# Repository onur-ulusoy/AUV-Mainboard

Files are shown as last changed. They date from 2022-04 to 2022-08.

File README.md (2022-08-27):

# Mainboard Hardware 

The Mainboard is the heart of our Autonomous Underwater Vehicle (AUV). This sophisticated board utilizes the power of the STM32H743 microcontroller, a high-performance device that serves as the brain of our AUV. The Mainboard's primary responsibilities are to facilitate real-time communication between various peripheral devices, translate high-level commands into specific device controls, distribute power to peripheral units, and provide robust system monitoring. Its unique role makes it a vital component in maintaining the smooth operation of the AUV, ensuring that each subsystem works in harmony to tackle the challenges of the underwater environment.

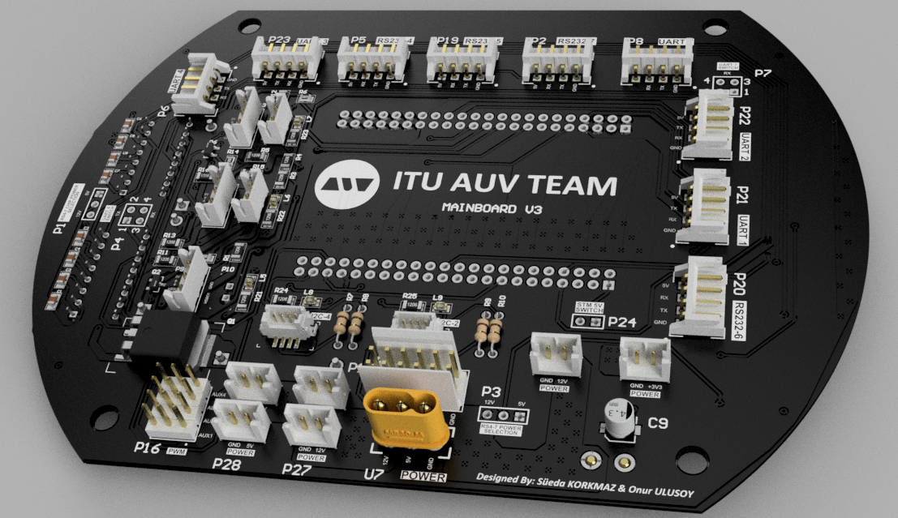
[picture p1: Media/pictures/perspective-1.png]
mb
<picture>    </picture>

This repository focuses Mainboard's hardware design. For more details on the firmware, visit the [Mainboard Firmware Repository](https://github.com/onur-ulusoy/auv-mainboard-firmware).

<picture>   dash </picture>

<p align="center">
    <a href="https://auv.itu.edu.tr/">
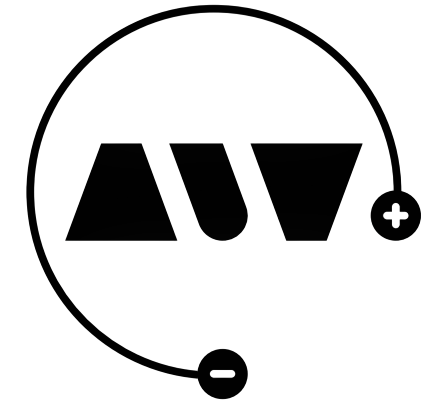
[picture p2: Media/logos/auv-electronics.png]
        
    </a>
</p>

<p align="center"><em >AUV Electronics 2022</em></p>

<picture>   dash </picture>

<p align="center">
    <a href="https://auv.itu.edu.tr/">
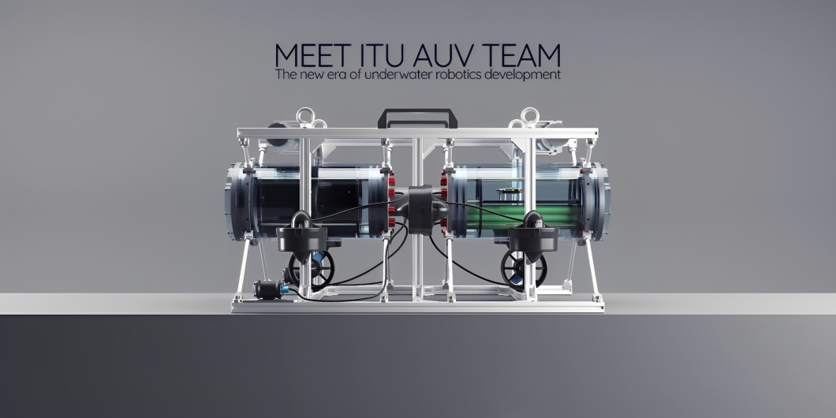
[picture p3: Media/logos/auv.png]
        
    </a>
</p>

<picture>   dash </picture>

<p align="center">
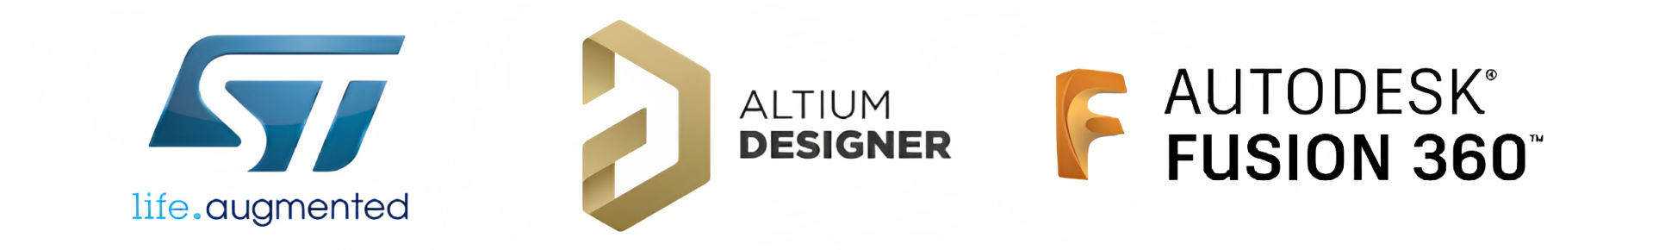
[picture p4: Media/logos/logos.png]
    
</p>

<picture>   dash </picture>

## Table of Contents
- [Mainboard Hardware](#mainboard-hardware)
  - [Table of Contents](#table-of-contents)
  - [Board Description](#board-description)
  - [Electronics Design](#electronics-design)
    - [Layer Structure](#layer-structure)
    - [Microcontroller](#microcontroller)
    - [Connectivity](#connectivity)
      - [UART](#uart)
      - [RS232](#rs232)
      - [I2C](#i2c)
    - [Power Circuits](#power-circuits)
      - [Power Inputs and Outputs](#power-inputs-and-outputs)
      - [High-Side Switch (HSS) Circuits](#high-side-switch-hss-circuits)
    - [Other Features](#other-features)
      - [PWM Channels](#pwm-channels)
      - [ADC's](#adcs)
    - [Selections](#selections)
      - [RS Power Chip Selection](#rs-power-chip-selection)
      - [STM 5V Switch](#stm-5v-switch)
      - [UART Switches](#uart-switches)
    - [Debug \& Lighting](#debug--lighting)
  - [Mechanical Design](#mechanical-design)
  - [Manufacturing](#manufacturing)
  - [Technologies Used](#technologies-used)
  - [Project Timeline](#project-timeline)
  - [License](#license)
  - [Gallery](#gallery)

## Board Description

Equipped with the high-performance microcontroller STM32H743, the Mainboard bridges the communication gap between the WARP Driver Board, the on-board computer Jetson Xavier, and other peripheral devices. This enables the Mainboard to effectively translate high-level system commands into specific device controls, ensuring optimal coordination among the various subsystems of the AUV.

Aside from its role as a communication facilitator, the Mainboard also handles the power management of the AUV. It distributes power to peripheral units via dedicated power headers, thereby maintaining a constant, controlled energy supply to each component. This power management function is vital for the reliable operation of each subsystem, ensuring they receive the correct power supply for their operations.

In an effort to strengthen diagnostics and status monitoring, the Mainboard is equipped with multiple LEDs, providing visual indicators of the system status and function. These visual indicators enhance system reliability by providing real-time feedback on the system's operation. Furthermore, they aid in troubleshooting by providing immediate visual cues on any parts of the system that may be experiencing issues.

## Electronics Design

For a comprehensive understanding of the Mainboard's intricate design and layout, you can always visit the [Schematic Sheets](/Schematic%20Sheets/). These detailed documents will provide you with valuable insights into the structure, connections, and functionalities of the board's various components.

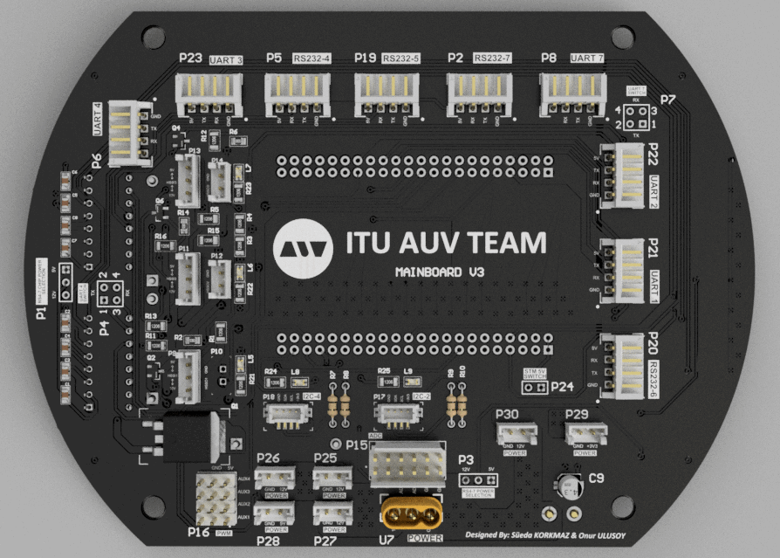
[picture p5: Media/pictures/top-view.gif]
<picture>    </picture>

### Layer Structure

Mainboard features a meticulously engineered 4-layer Printed Circuit Board (PCB) structure, designed using the advanced capabilities of Altium Designer. At the heart of the layout are the power and ground layers, smartly employed as inter-layers within the design.

These inter-layers serve more than just conducting electricity or acting as a return path. Their positioning within the inner layers of the board provides a close and uniform ground plane across the board, significantly reducing loop inductance for high-speed signals. This layout strategy inherently offers enhanced signal integrity and reduces the susceptibility of the board to electromagnetic interference (EMI), which could otherwise compromise the reliability and performance of the system.

Moreover, by sandwiching the power and ground planes between the outer signal layers, the PCB achieves a better thermal management. Heat generated by components mounted on the outer layers can be efficiently spread across the plane layers and dissipated, ensuring that the board components always remain within safe operating temperatures. This design is particularly critical in a demanding application environment such as an Autonomous Underwater Vehicle, where managing thermal behavior is crucial to maintain overall system reliability and longevity.

The 4-layer structure, thus, adds significant robustness to the Mainboard, enabling it to effectively support complex and power-intensive operations while ensuring optimal performance and safety.

For a more detailed examination of the board layers and the overall PCB structure, you can visit the file [MAINBOARD.PcbDoc](/MAINBOARD.PcbDoc).

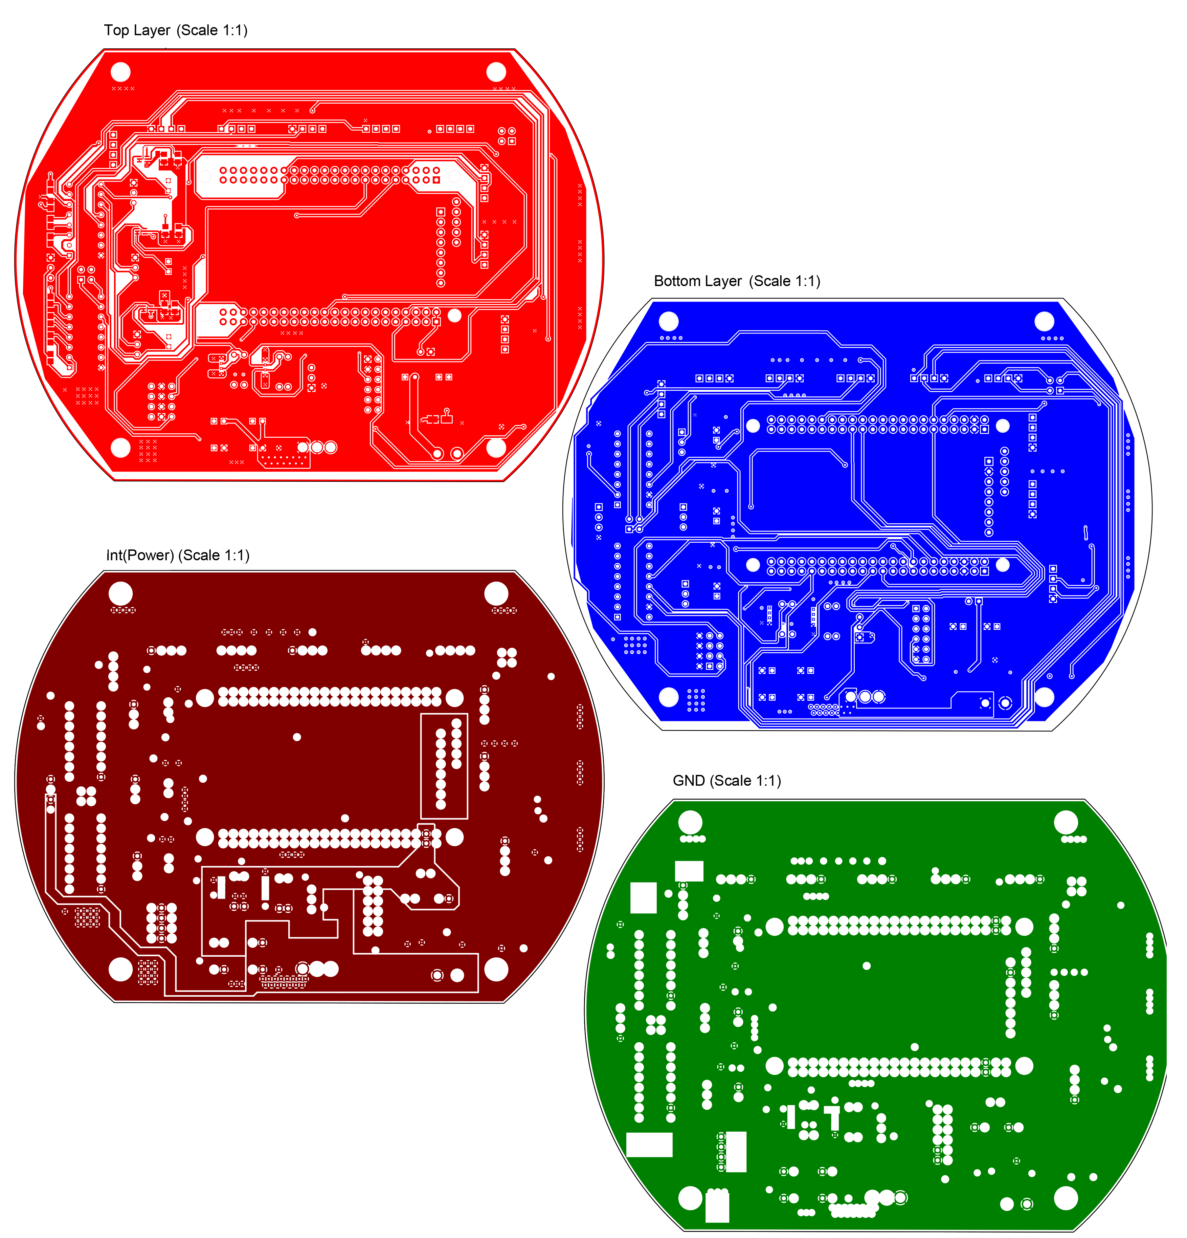
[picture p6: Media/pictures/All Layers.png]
<picture>    </picture>

### Microcontroller
At the heart of the Mainboard is an STM32H743 microcontroller, a powerful, high-performance device that provides the processing muscle needed to handle the complexities of operating an Autonomous Underwater Vehicle.

The firmware for the microcontroller has been developed and customized for the STM32H743, ensuring precise control and superior performance of the hardware. In order to manage tasks efficiently, we've integrated the FreeRTOS - a feature-rich real-time operating system. This system facilitates effective task scheduling and management, thereby ensuring that critical operations such as communication handling, power management, and device control are handled in a timely and efficient manner.

Just as it is with the WARP Driver Board, the priority with the Mainboard's microcontroller is to manage high-importance real-time tasks, such as power distribution and communication processing. FreeRTOS provides the necessary tools to ensure these tasks are dealt with promptly, while also maintaining the performance of lower-priority tasks. This symbiotic relationship between the microcontroller's firmware and the real-time operating system allows the Mainboard to perform its key tasks with optimal precision, efficiency, and reliability.

<p align="center">
    <a>
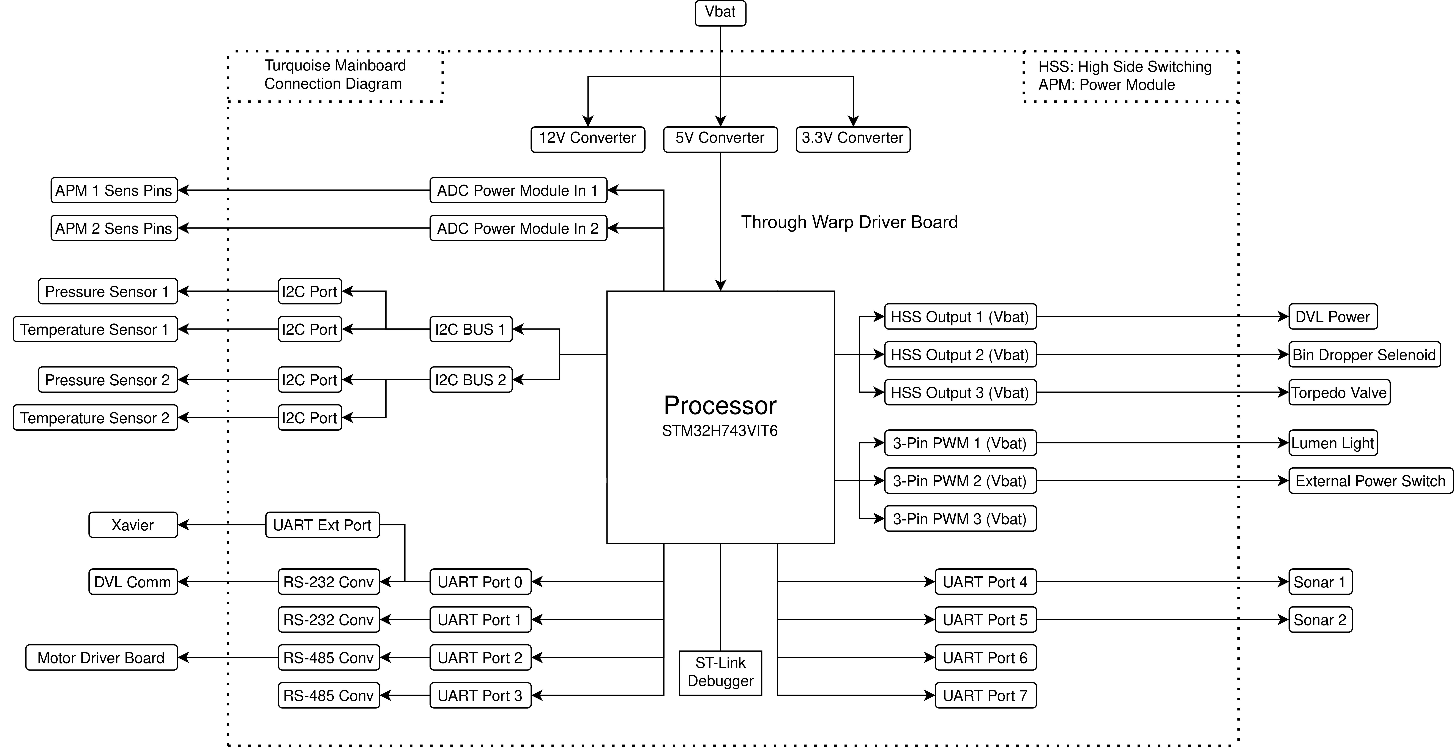
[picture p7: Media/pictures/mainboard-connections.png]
        
    </a>
</p>

### Connectivity
The Mainboard offers a wide range of connectivity options to interface with the various devices and subsystems that form the architecture of our AUV. This is essential for establishing efficient communication between the different units.

#### UART
The board is equipped with five UART (Universal Asynchronous Receiver/Transmitter) headers directly connected to the microcontroller. These headers primarily serve to establish communication with the sonars in our AUV system. The use of UART facilitates reliable data transfer, a crucial feature in our setup.

#### RS232
The Mainboard features four RS232 headers that are connected to the UARTs of the microcontroller via an RS232 interface IC. This arrangement is especially useful for long-distance communications as it can effectively resist electrical noise that may corrupt data. The RS232 interface is primarily used for communication with the Jetson Xavier, the DVL (Doppler Velocity Log), and the WARP Driver Board.

RS232 and UART Headers of the Mainboard:

<p align="center">
    <a>
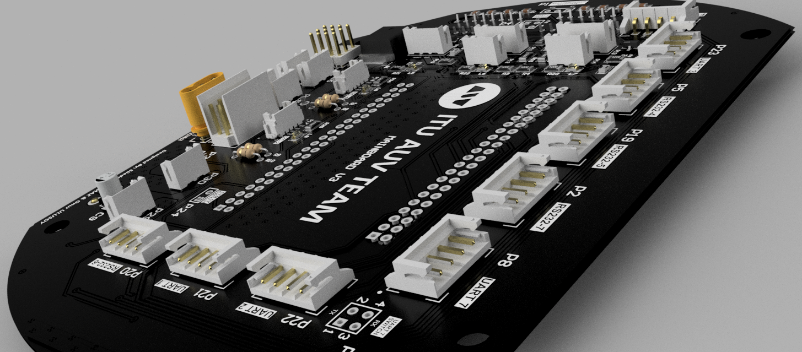
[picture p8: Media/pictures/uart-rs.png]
        
    </a>
</p>

#### I2C
In addition, the board includes two I2C (Inter-Integrated Circuit) headers, which are directly connected to the microcontroller. I2C is a highly effective method for short-distance communication and is utilized in this system for exchanging data with pressure and temperature sensors. This bus system enables the microcontroller to access and control these sensors, making real-time monitoring of the AUV's environment possible.The I2C circuits also have their own LEDs to provide real-time monitoring of communication status.

<p align="center">
    <a>
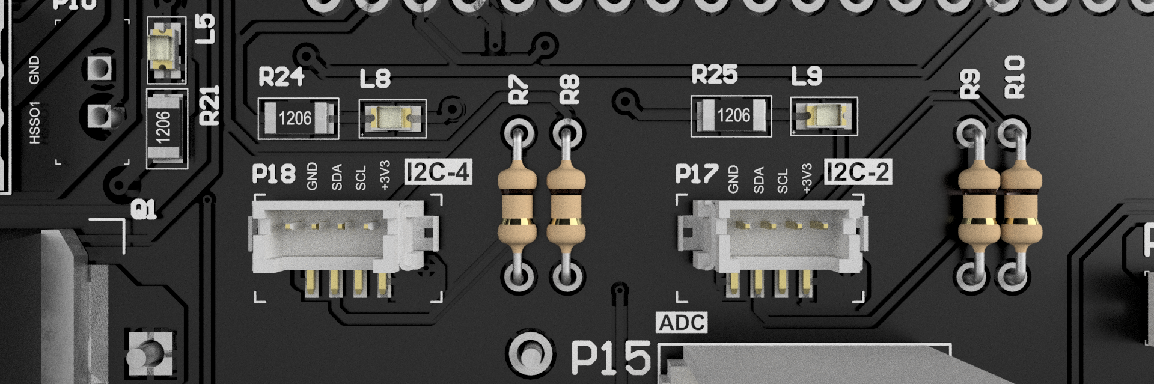
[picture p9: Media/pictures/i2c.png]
        
    </a>
</p>

### Power Circuits

#### Power Inputs and Outputs

The Mainboard is designed to receive power inputs of 12V and 5V, along with GND (ground). It possesses several power output connectors that can effectively power peripheral units such as the onboard computer, sensors, and its own microcontroller. These connectors ensure reliable and efficient power distribution across the system, supporting the operation of all connected devices.

<p align="center">
    <a>
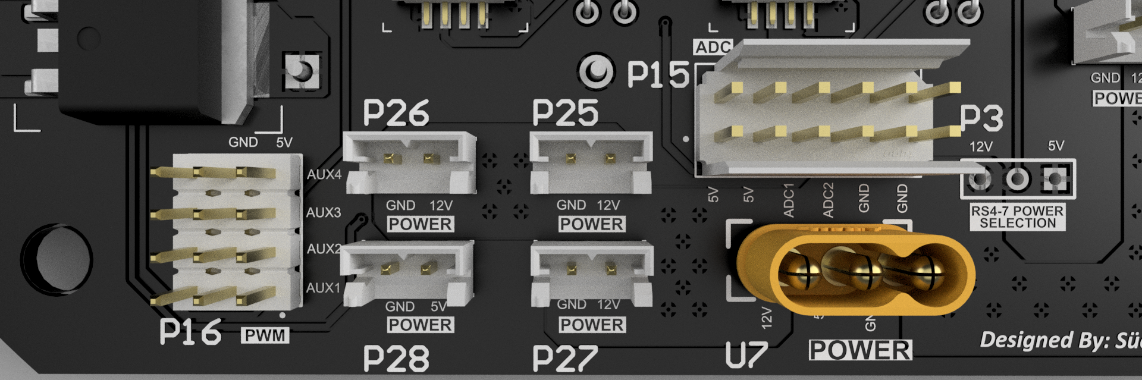
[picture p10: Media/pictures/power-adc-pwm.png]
        
    </a>
</p>

#### High-Side Switch (HSS) Circuits

The Mainboard is equipped with three High-Side Switch (HSS) circuits. These circuits are primarily used to control high-power loads, such as the bin dropper solenoid, the torpedo valve, and the Doppler Velocity Log (DVL). The HSS circuits can be powered with either 12V or 5V and are controlled through the GPIO pins of the microcontroller. They also have their own LEDs to provide real-time monitoring of their status. The HSS circuits provide safe and efficient switching operations, ensuring reliable control over these critical components of the AUV.

Selenoid driving with the HSS circuit in simulation can be seen below:

<p align="center">
    <a>
        
    </a>
</p>

3 HSS placement on the PCB:

<p align="center">
    <a>
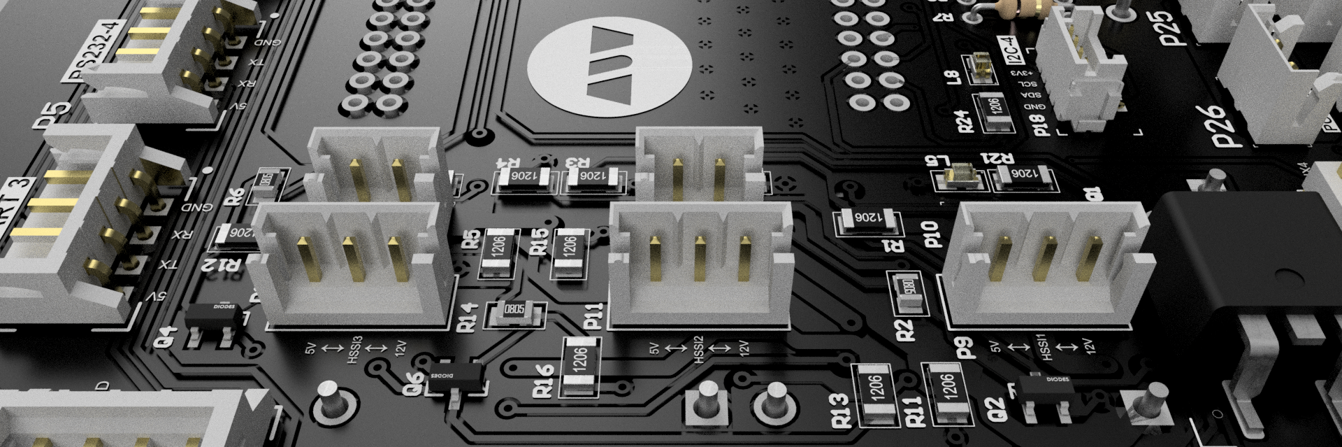
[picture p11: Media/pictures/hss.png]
        
    </a>
</p>

### Other Features

#### PWM Channels
The Mainboard provides support for three Pulse Width Modulation (PWM) channels. These channels can be utilized to drive and control peripheral components like the Lumen Light and an External power switch. The ability to manipulate the duty cycle of these signals offers precise control over these devices, allowing for adaptive operation according to varying underwater conditions.

#### ADC's
In addition to its various connectivity options, the Mainboard is equipped with two Analog to Digital Converters (ADCs) integrated within the microcontroller. These ADCs play a crucial role in the Sens APM function, converting the analog measurements into digital data for further processing and evaluation by the microcontroller.

### Selections

In the design of the Mainboard, much thought has been given to providing flexibility and configurability. Various selections have been included in the board's design to manage connections physically and ensure operational continuity.

#### RS Power Chip Selection

The Mainboard includes a selection feature for the RS power chip. This allows for a switch between different power chips as per the requirement, ensuring the most efficient operation for different devices connected via the RS232 interface.

<p align="center">
    <a>
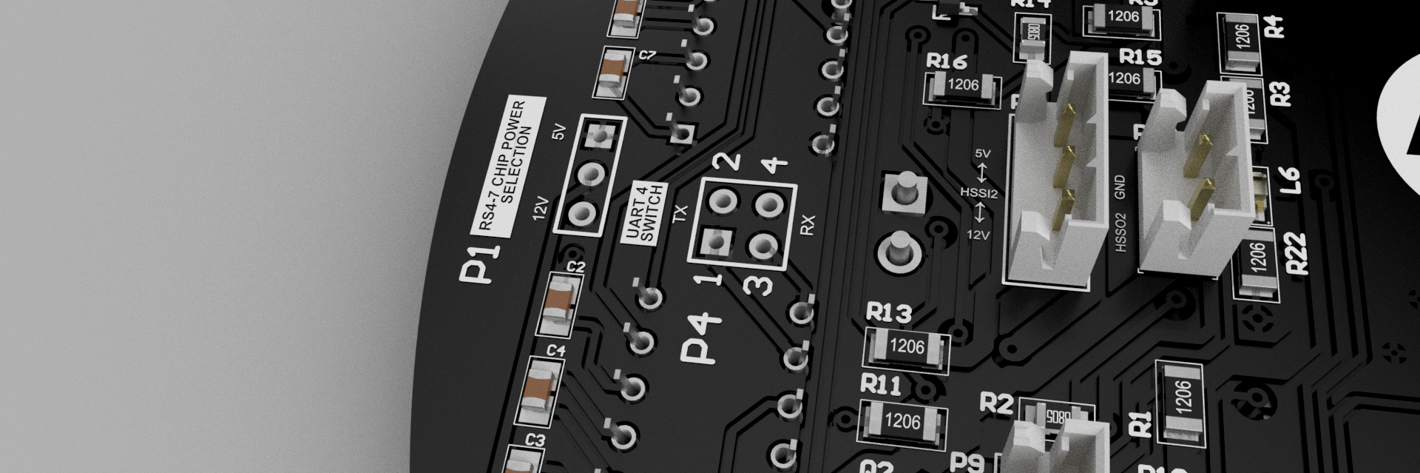
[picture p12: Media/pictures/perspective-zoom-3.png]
        
    </a>
</p>

#### STM 5V Switch

The Mainboard also has a provision to physically control the power supply to the STM32 microcontroller. With the STM 5V switch, the supply to the microcontroller can be turned on or off without affecting the rest of the board, useful for testing and debugging.

#### UART Switches

Furthermore, the board features UART switches to manage the connections with the devices interfaced through the UART headers. These switches enable direct control over the communication lines, allowing for convenient management of device connections. 

These selection features underscore the Mainboard's adaptability, allowing for a high degree of customization and control over the board's operation. They add an additional layer of robustness, enabling the board to continue operating efficiently even under changing conditions and requirements.

<p align="center">
    <a>
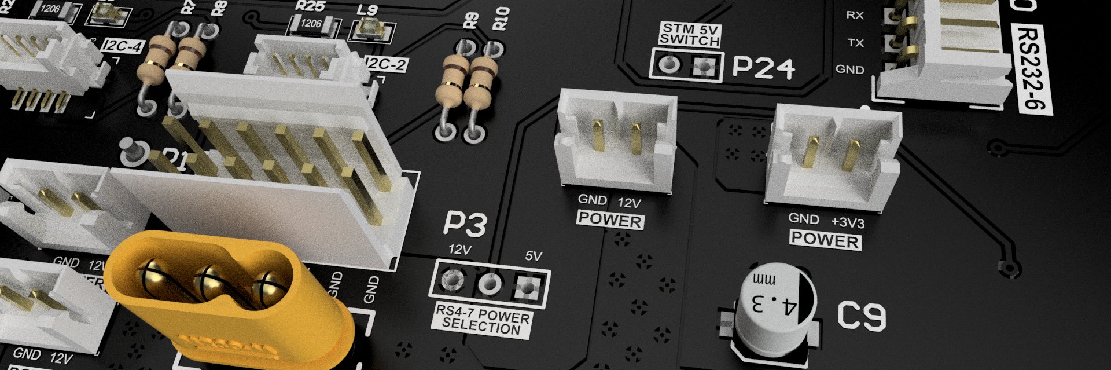
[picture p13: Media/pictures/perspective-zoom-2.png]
        
    </a>
</p>

### Debug & Lighting

Ensuring effective monitoring and debugging of the Mainboard is crucial to its smooth operation and management. To this end, the Mainboard has been designed with a comprehensive array of LEDs, which serve the dual purpose of debugging support and lighting enhancement.

<p align="center">
    <a>
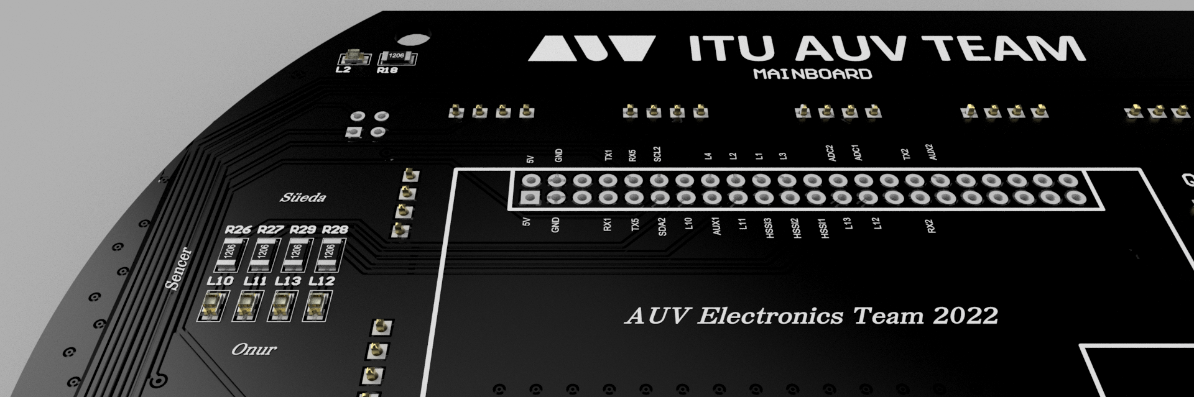
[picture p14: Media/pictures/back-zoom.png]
        
    </a>
</p>

## Mechanical Design

The mechanical design of the Mainboard is meticulously crafted to fit within the specific constraints of the Autonomous Underwater Vehicle (AUV). The board is designed to mount into the front tube of the AUV, matching the tube's form factor for an optimized fit.

This is achieved by fastening the board through four corner holes that align with the mounting points within the tube. This approach ensures that the Mainboard remains securely positioned during the AUV's underwater operations, allowing it to endure the potential rigors of the marine environment.

Moreover, this mechanical setup provides convenient accessibility to the board, which aids in the ease of maintenance and part replacements when required. The combination of a compact form factor and a secure mounting design allows the Mainboard to effectively fulfill its crucial roles in power distribution, communication, and control within the AUV.

<p align="center">
    <a>
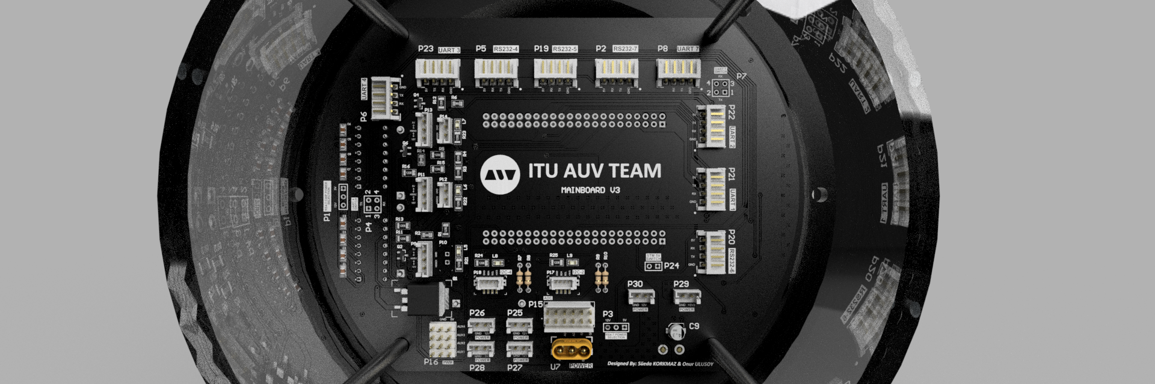
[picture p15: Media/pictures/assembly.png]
        
    </a>
</p>

<picture>   dash </picture>

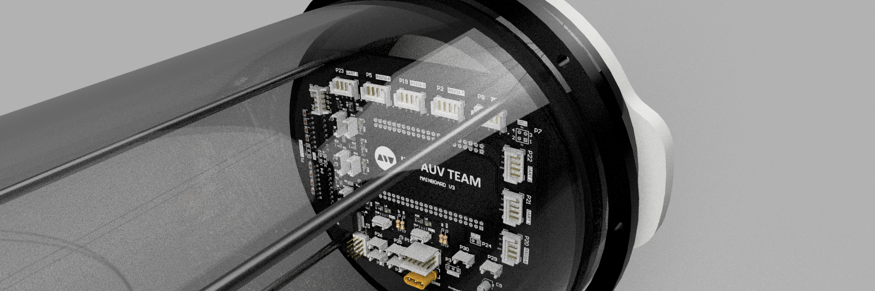
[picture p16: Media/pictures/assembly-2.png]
assembly
<picture>    </picture>

## Manufacturing 

In order to ensure that our Mainboard design meets the specific manufacturing specifications of our chosen PCB manufacturer, we have employed the Design Rule Check (DRC) feature in Altium Designer. You can check the detailed report of this rule verification in the output files directory. 

The necessary Gerber files, which include the comprehensive manufacturing details needed to transform our electronic design into a tangible board, are compiled in the [Output](/Output) directory.

We have manufactured and prototyped three versions of the Mainboard with JLC PCB, using the feedback and insights gained from each iteration to continuously refine the design and functionality.

The final products, the manufactured boards, are currently installed on our Autonomous Underwater Vehicle and can be viewed at ITU Bisiklet Evi. This gives interested parties a chance to see our work firsthand and appreciate the tangible representation of our intricate electronics design.

Below you can see a picture from Version 2 of Mainboard:

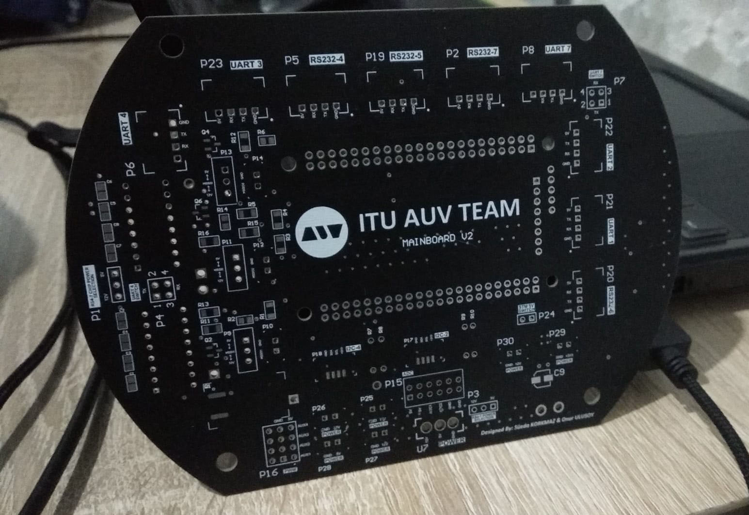
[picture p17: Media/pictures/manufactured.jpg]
<picture>    </picture>

## Technologies Used

- **Altium Designer:** We utilized this advanced PCB design software to craft the complex four-layer design of the board. Altium Designer's intuitive interface and comprehensive features allowed us to design and validate the board's electronic components efficiently.

- **STM Technologies:** Our system's microcontroller, the STM32 development board, comes from the STM technology suite. It forms the heart of our design, managing the sophisticated tasks within the AUV.

- **Fusion 360:** For the mechanical design and rendering of the Mainboard, we used Autodesk Fusion 360. This powerful CAD/CAM tool allowed us to visualize and perfect the physical design and ensure its compatibility within the AUV. It also provides us to integrate with mechanics team.

- **Simulation Programs:** To validate and optimize our design, we made extensive use of electronic simulation programs such as Falstad and LTSpice. These tools enabled us to simulate the performance of our electronic circuits under various conditions, allowing us to refine and perfect the design before moving to manufacturing.

## Project Timeline
This project is a proud contribution of the 2022 Electronics Team of the ITU AUV (Istanbul Technical University's Autonomous Underwater Vehicle) Team. Performed in the intervals Dec 2021 - Aug 2022.

Süeda Korkmaz and Onur Ulusoy, members of the team, meticulously carried out the comprehensive design and production of PCBs and circuits using Altium Designer. Three distinct versions were manufactured with the cooperation of JLCPCB. The team also prepared and ordered all electronic components required, and undertook the detailed process of typesetting.

The PCB has found its home at the ITU Bisiklet Evi, in the AUV section of the atelier, where it has been installed on the vehicle.

We extend our gratitude towards our mindset consultant, Sencer Yazıcı, whose guidance has been instrumental throughout the process.

Onur Ulusoy's diligent efforts are to be acknowledged in providing a visually cohesive and detailed representation of our project. His work encompassed the complete set of documentation, including preparing and improving 3D models, producing high-quality renders, and ensuring effective visualization of our design.

<p align="center">
    <a>
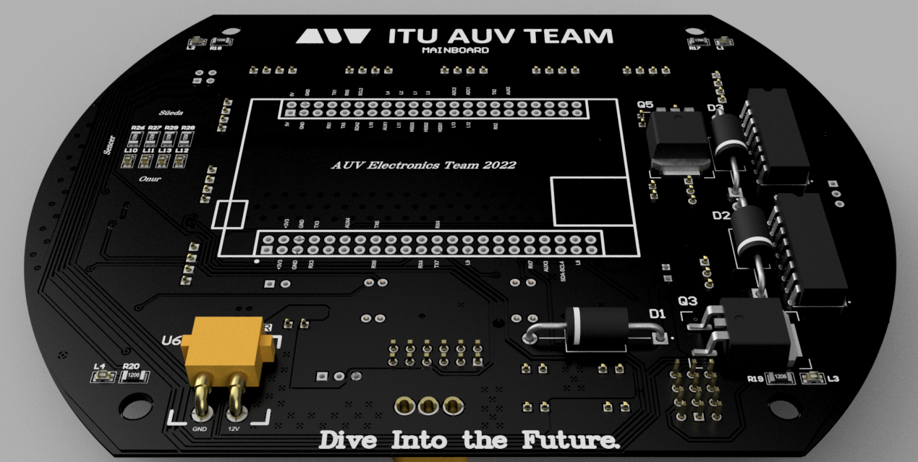
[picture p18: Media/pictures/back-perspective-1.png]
        
    </a>
</p>

## License



This repository contains the design and documentation for the AUV Mainboard, a project PCB by the ITU AUV Team Electonics 2022.

**Licensor:** ITU AUV Team 2022 Electronics

This work is licensed under a [Creative Commons Attribution-NonCommercial-ShareAlike 4.0 International License](http://creativecommons.org/licenses/by-nc-sa/4.0/). You can view the full terms of the license in the [LICENSE](./LICENSE) file in this repository.

**Please note:** When using this project, you must give appropriate credit, including a link to the original GitHub repository: [https://github.com/onur-ulusoy/AUV-Mainboard](https://github.com/onur-ulusoy/AUV-Mainboard)

## Gallery

For a visual tour of the MainBoard, you can explore our [gallery](https://onur-ulusoy.github.io/AUV-Mainboard/Media/gallery.html). Here you'll find detailed images showcasing the design and implementation of the board.

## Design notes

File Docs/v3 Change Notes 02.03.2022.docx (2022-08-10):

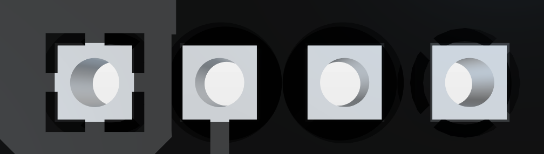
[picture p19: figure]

1)

4’lü connector (P16, P17, P18, P4, P1, P2, P3, P19) delikleri büyüdü.

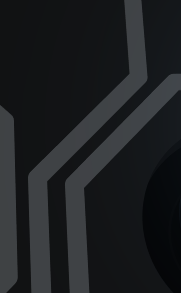
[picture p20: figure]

2)

Net (trace/yol) kalınlıkları 10 mil→15 mil ‘e çıktı.

3)

Şematik hatası giderildi ve pcb’ye güncellendi.

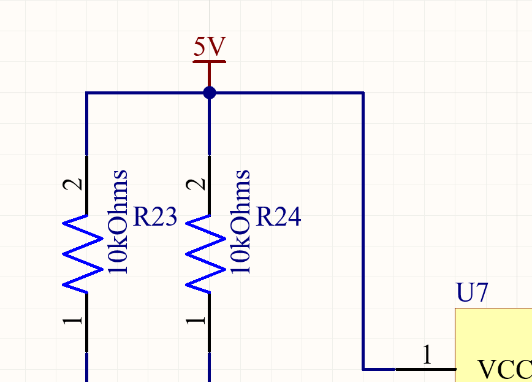
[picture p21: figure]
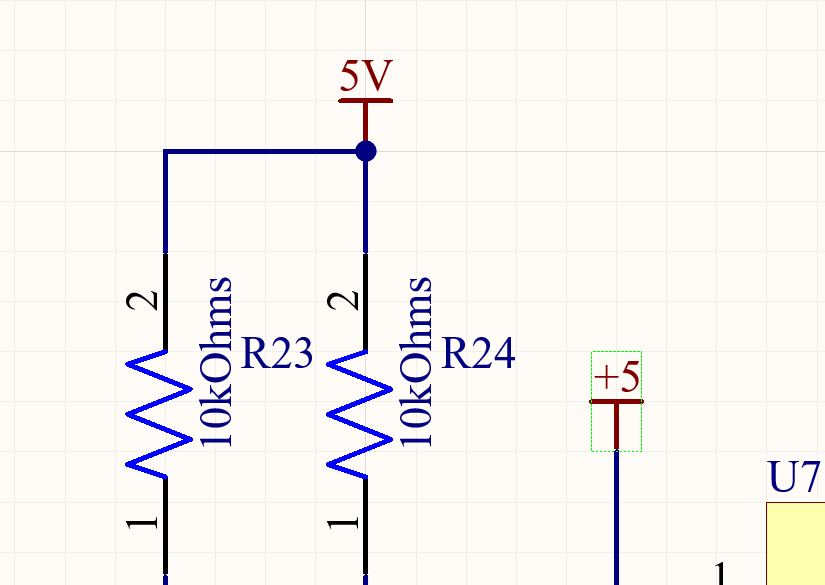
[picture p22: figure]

4)

R19, 20, 21, 22, 25, 26, 11, 12, 13, 14, 1, 2, 3, 4 dirençlerin tamamı through hole dip yapıldı.

5)

Aşağıdaki delikler 74’ten 98’e büyüdü .

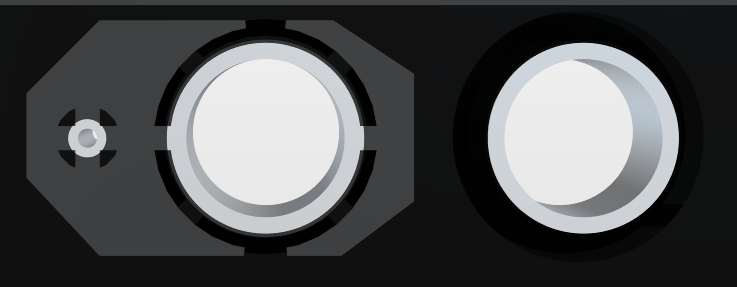
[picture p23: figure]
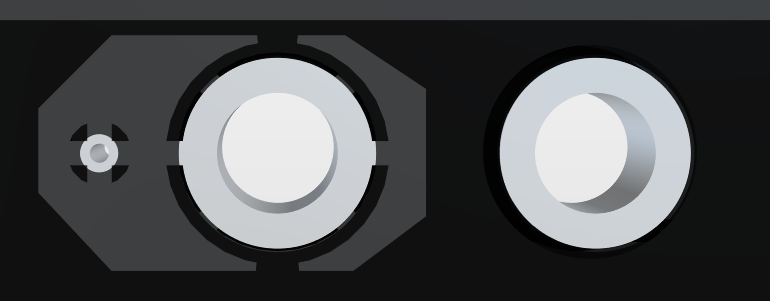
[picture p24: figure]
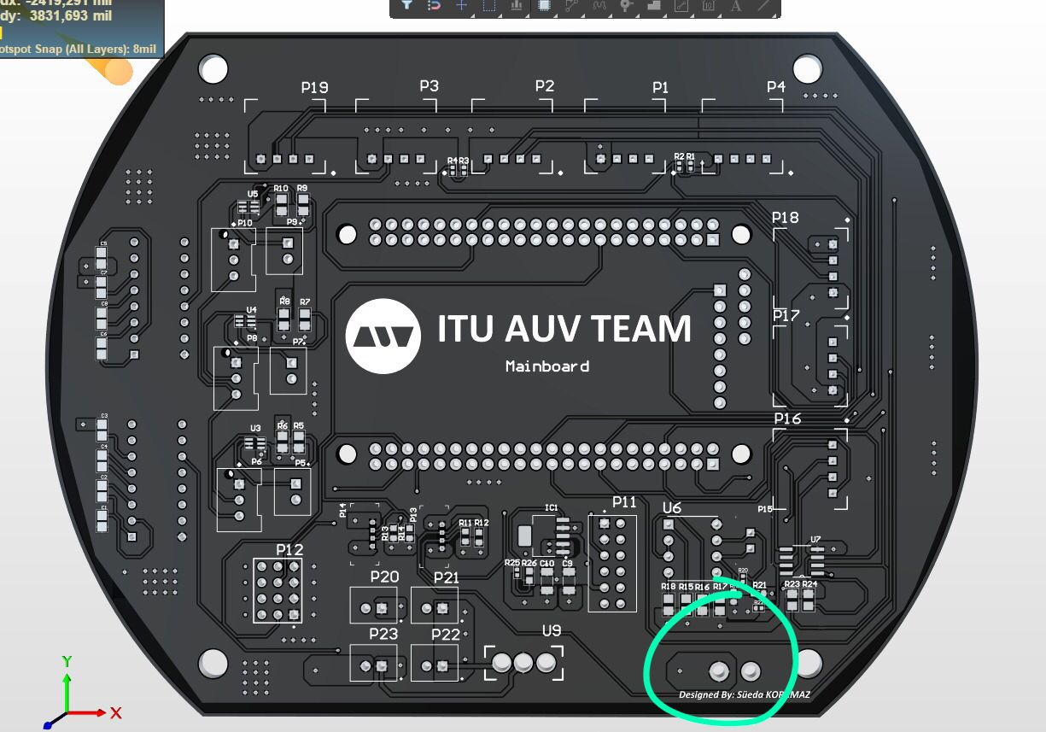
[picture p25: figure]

6)

RS485 -> RS 232 çevrilmesi gerekiyor, dizayn problemi olduğundan dokunmadım

Güç bağlantılarının ve DRC hatalarının kontrol edilmesi gerek.

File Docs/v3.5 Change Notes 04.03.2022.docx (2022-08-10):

V3 branchi main board 2. part değişimler

1)

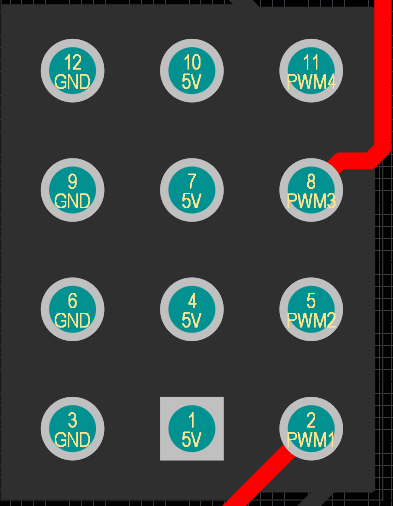
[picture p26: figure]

P12 Orta ve sağ değişti. (Resimler top layer)

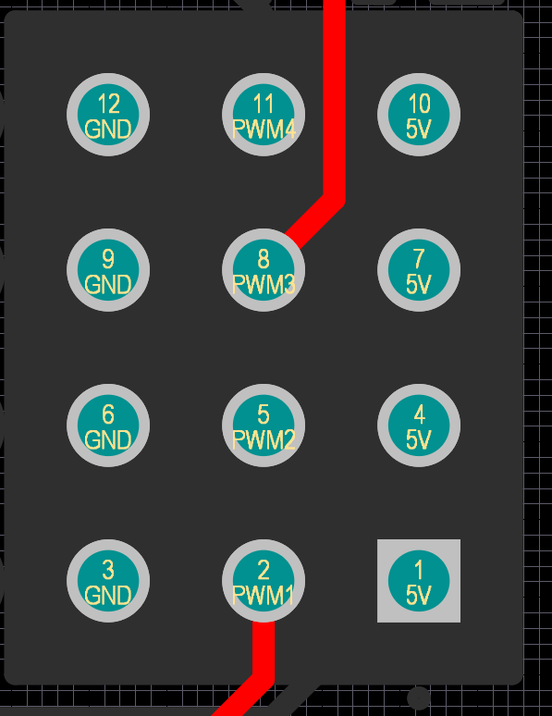
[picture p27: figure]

2)

U9 5V Güç net kalınlığı 15 mil→50 mil , 12V’lar polygon.

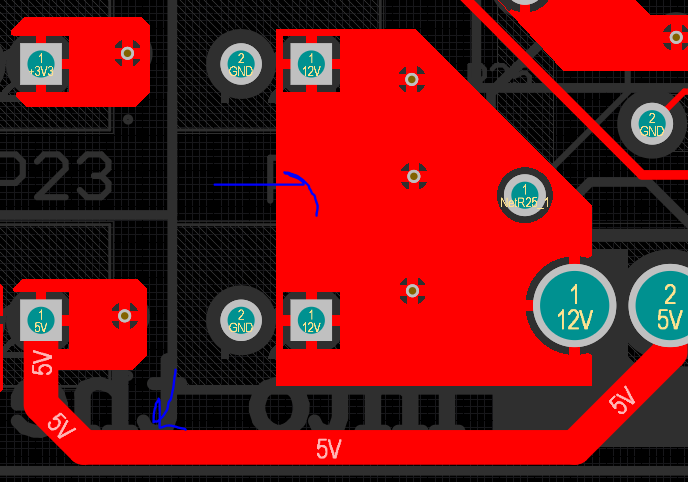
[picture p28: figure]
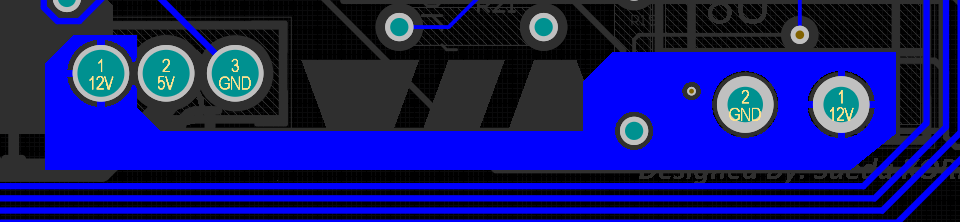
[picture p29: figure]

Diğer güç yolları da DRC kuralları elverdiğince artırıldı.

3)

DIP direnç çapları 1mm’ye çıktı.

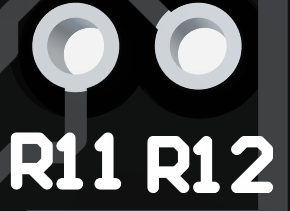
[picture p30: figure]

4)

Connector 3d modelleri değişti, sağdaki connectorler sağa bakacak şekilde 360 derece döndürüldü.

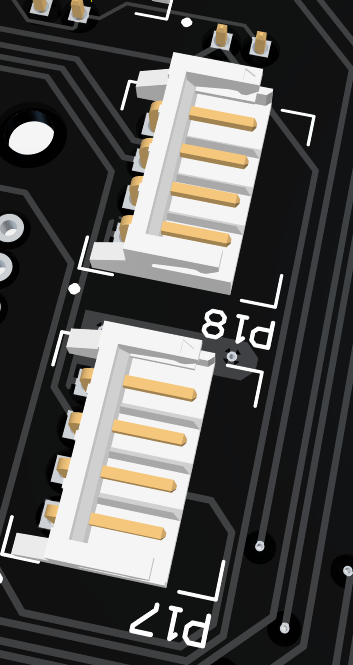
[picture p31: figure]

5) Bazı connectorlerin yanına yazılar geldi ve gelecek.

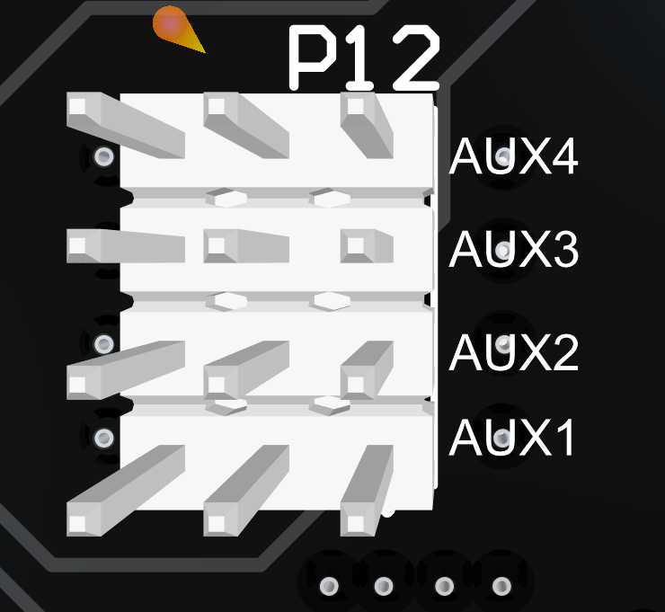
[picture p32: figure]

6) 0ohm dirençlerin yerine bridge headerları geldi, alt katmana ekledim çünkü görüntüyü bozuyordu ve pek yer yoktu.

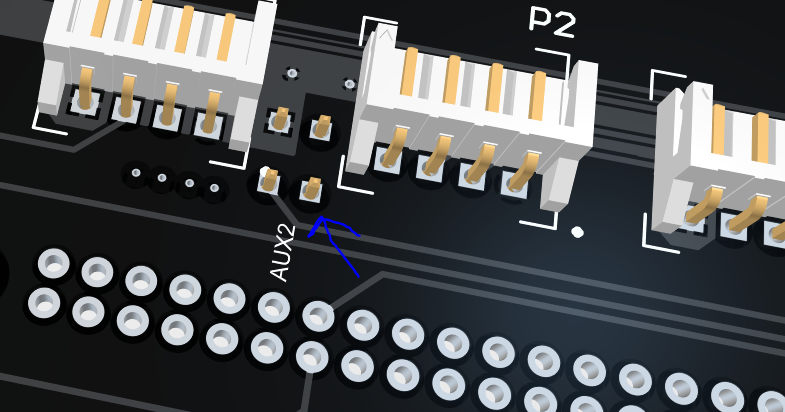
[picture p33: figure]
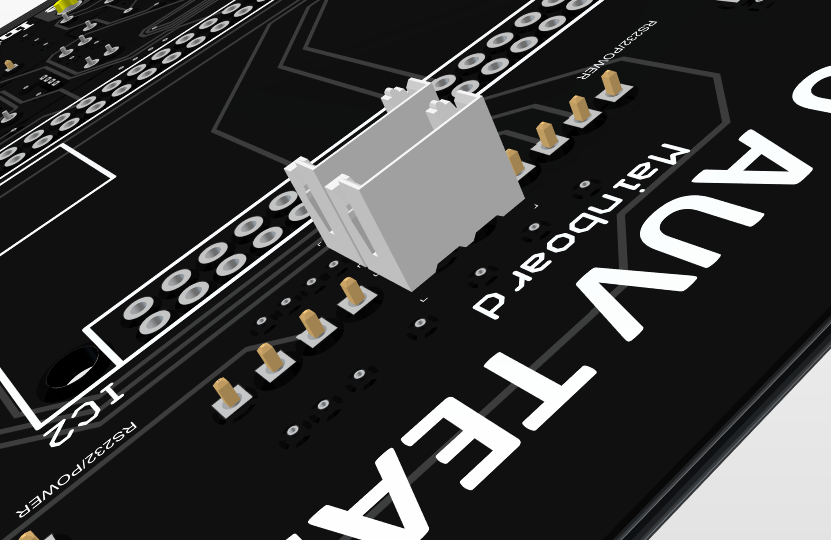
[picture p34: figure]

Kartın arkası Kartın önü

Bu versiyonda harcanan toplam zaman: 7-8 saat.

V4’te yapılacaklar:

Tüm connectorlerde vs. 1 numara gnd olacak ve komponent ona göre 360 derece dönecek.

Gereksiz uzatılmış olma ihtimali olan traceler kontrol edilecek.

Güç bağlantı kalınlıkları kontrol edilecek, özellikle 5V ve genel polygon.

Baskı için DRC hataları giderilecek.

Sorular:

1) Güç bağlantıları, 12V’lar bağlantılı değil örneğin (şekilde), GND’ler bağlantılı değil, 5V’ların hepsini polygon ile halledebilecek miyiz vs.

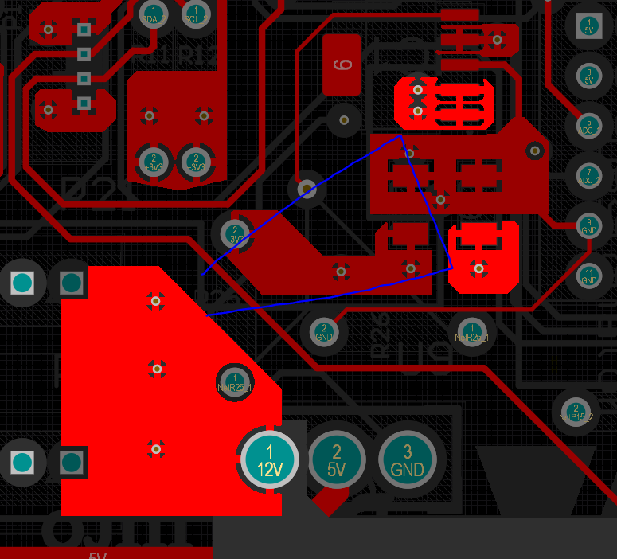
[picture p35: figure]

2) Okla gösterilen yerlerin ince olması

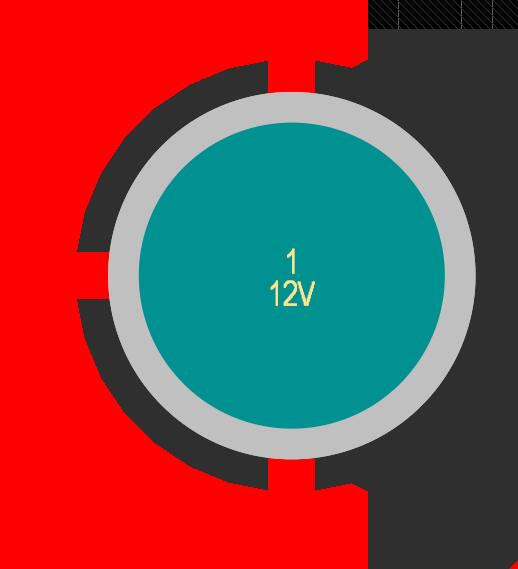
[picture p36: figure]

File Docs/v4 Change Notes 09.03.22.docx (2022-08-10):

Mainboard v4 değişiklikleri

1) Top overlaydeki yerleri uygun olmayan yazıların yerleri düzenlendi.

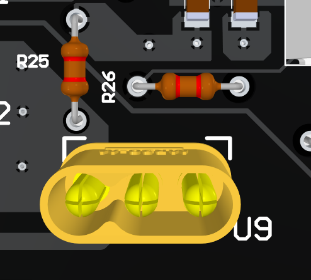
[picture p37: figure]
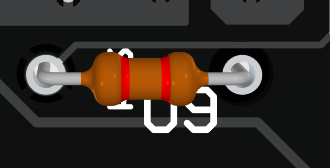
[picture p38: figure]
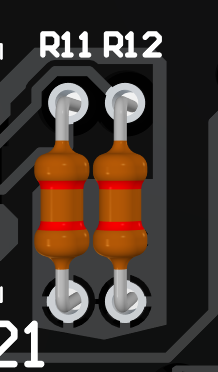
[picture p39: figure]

2) Headerlar GND→1 olacak şekilde ayarlandı.

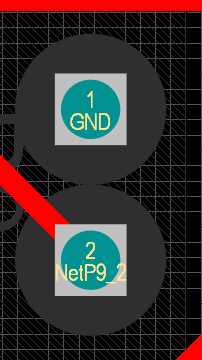
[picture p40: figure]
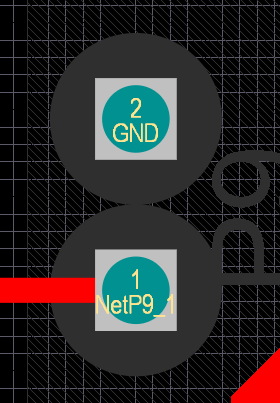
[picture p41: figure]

3) Kıyıda köşede kalan ince traceler kalınlaştırıldı ve güzel olmayanlar düzeltildi. Gerilim tracelerinin hepsi kontrol edildi, olabildiğince kalınlaştırıldı.

4) Tüm güç bağlantıları çok dikkatlice kontrol edildi ve düzeltildi (çook uzun sürdü ve bayağı iyi oldu), görebildiğim kadarıyla eksik bağlantı yok, isterseniz beraber de bakarız:

12V:

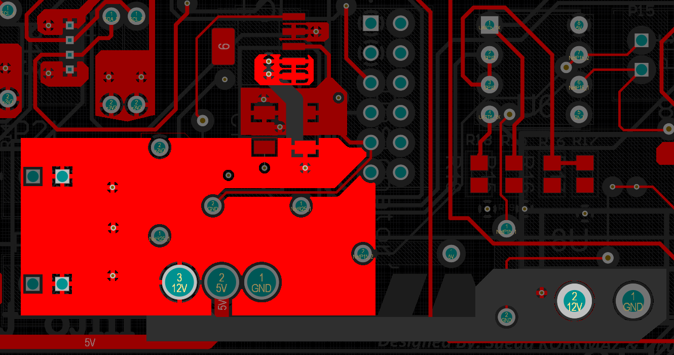
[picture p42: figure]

3.3V:


GND:


5V:

Top layer:


Bottom layer:


Bu versiyona harcanan toplam zaman: 8-9 saat.

Eksik kalan sadece:

RS 485 değişecek


RS 232 kombinezon devre şematiği:


Burayı RS 232 kombinezon devreleriyle değiştireceğim ancak headerlar aynı değil? Sağdaki header dörtlü mü yapılacak? GPIO bağlantı yolu silinecek.

Ayrıca burada 2 tane header var.

Şu header’a ne olacak?

Ayrıca RS 485 ŞEMATİĞİNDE,

Max 488 entegresiyle kurulmuş başka bir kombinezon devre var. Bunun tam olarak ne olduğunu anlamadım. Bunu da mı RS 232 kombinezon devresiyle mi değiştireceğim?


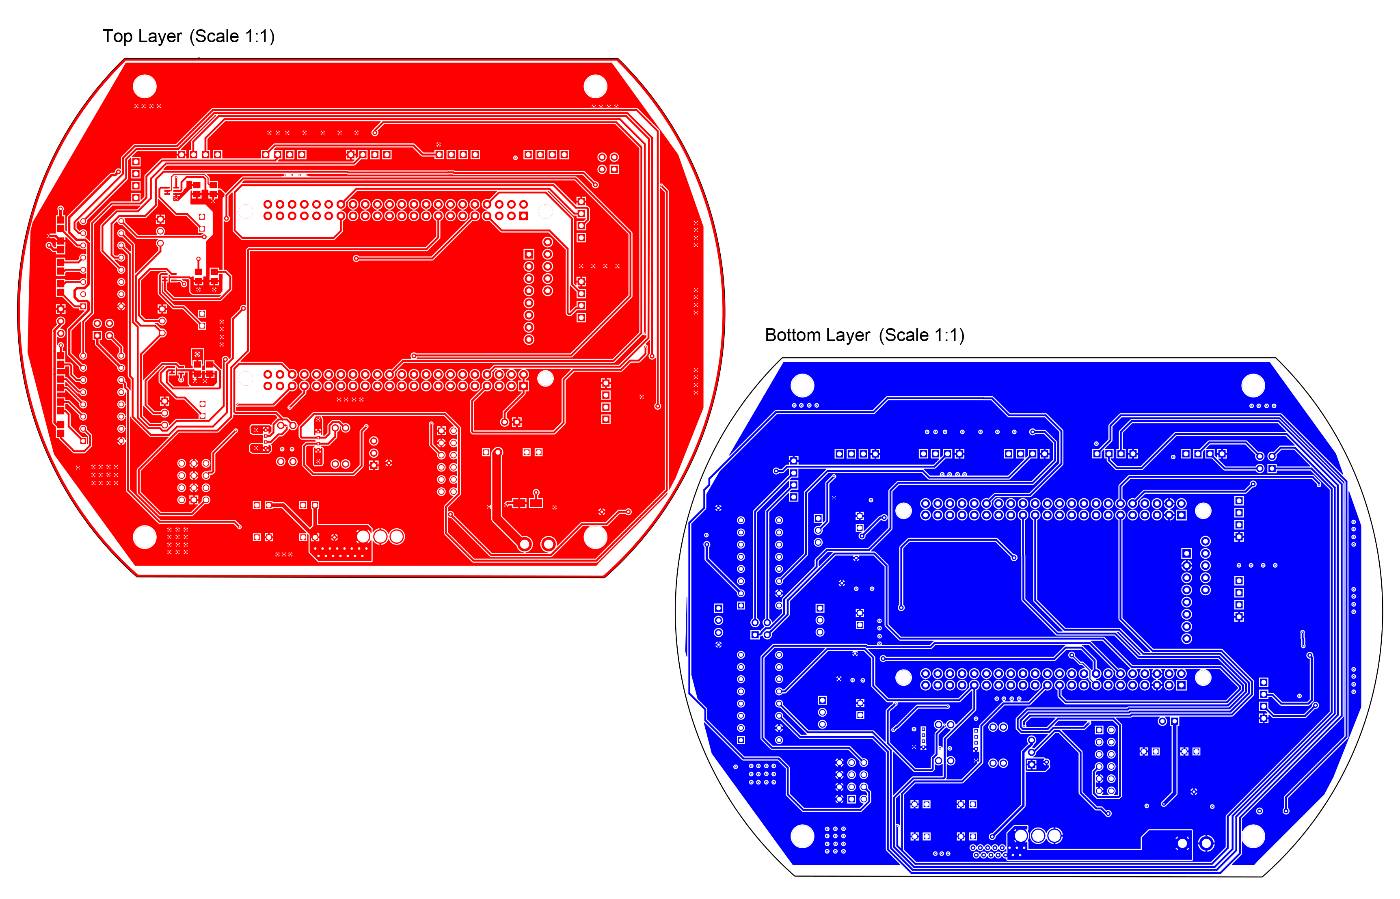
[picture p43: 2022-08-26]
Media/pictures/Top-Bottom Layers.png

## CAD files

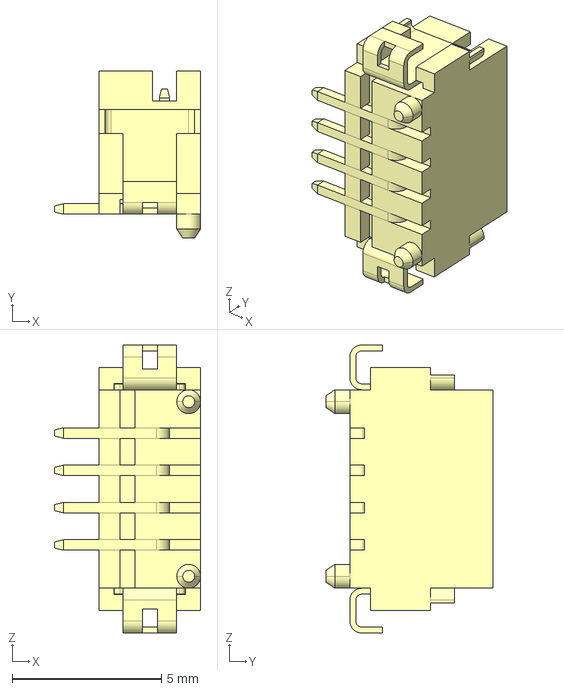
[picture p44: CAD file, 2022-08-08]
3D Models/DF13-4P-1.25V--3DModel-STEP-1.STEP
4.90 x 5.60 x 9.65 mm

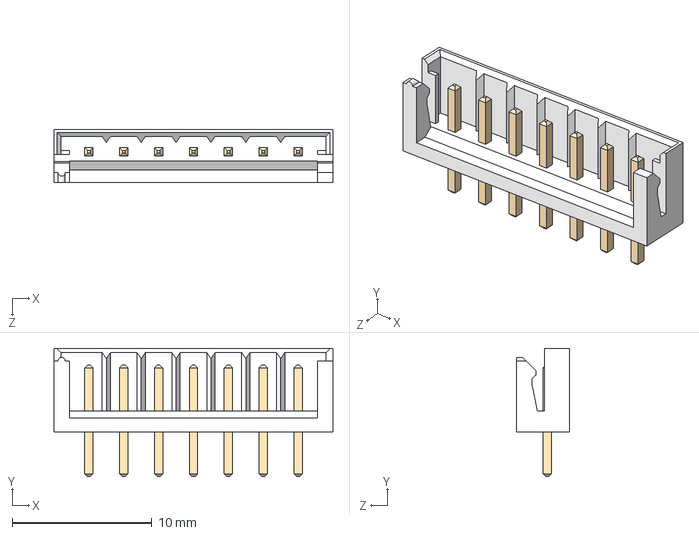
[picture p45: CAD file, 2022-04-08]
3D Models/EH 2.50 Connectors/STEP/BB-Top_Entry_Type/JST-B7B-EH-A.STEP
20.0 x 9.20 x 3.80 mm

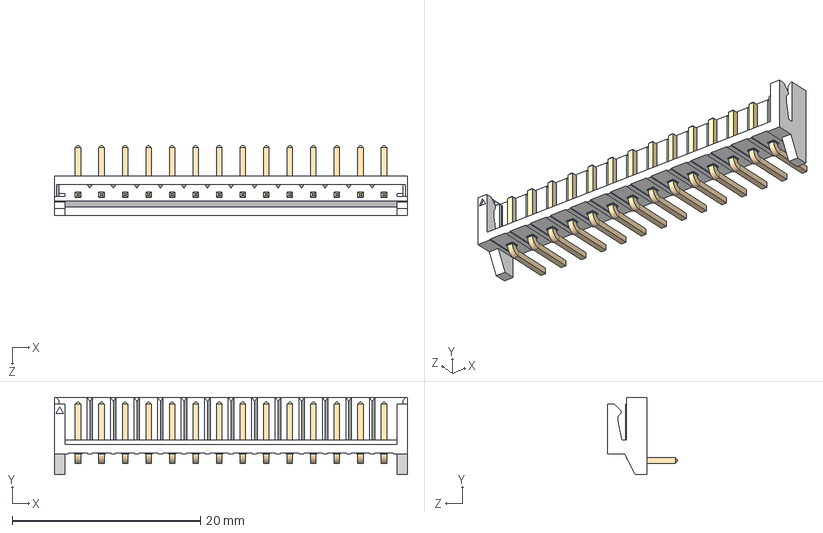
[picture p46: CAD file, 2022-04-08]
3D Models/EH 2.50 Connectors/STEP/SB-Side_Entry_Type/JST-S14B-EH-A.STEP
37.5 x 8.20 x 7.40 mm

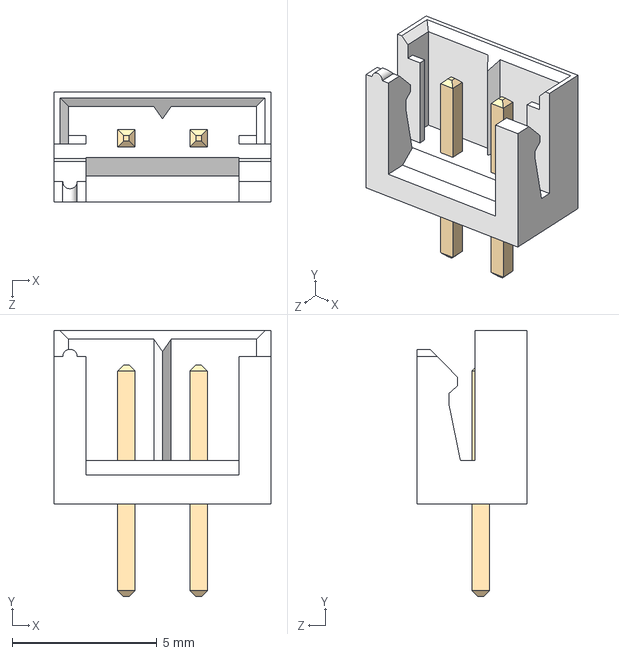
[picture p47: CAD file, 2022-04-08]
3D Models/EH 2.50 Connectors/STEP/BB-Top_Entry_Type/JST-B2B-EH-A.STEP
7.50 x 9.20 x 3.80 mm

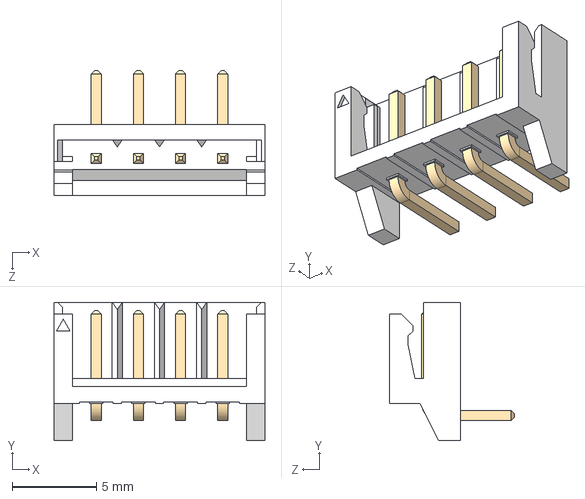
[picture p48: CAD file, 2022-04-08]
3D Models/EH 2.50 Connectors/STEP/SB-Side_Entry_Type/JST-S4B-EH-A.STEP
12.5 x 8.20 x 7.40 mm

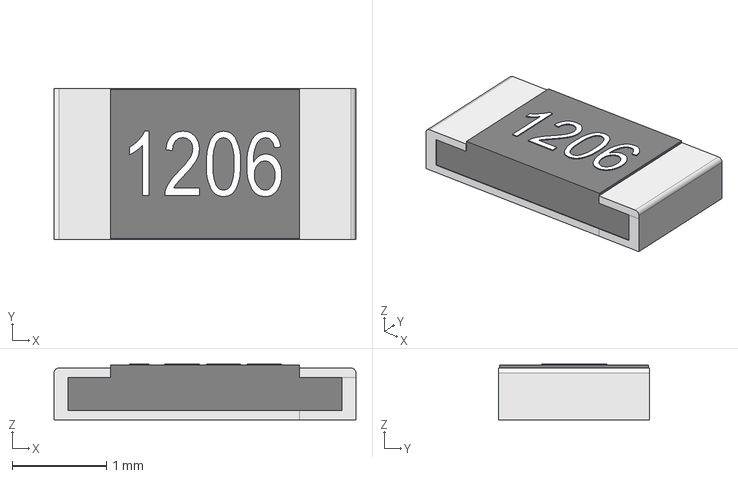
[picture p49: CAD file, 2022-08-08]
3D Models/resistencia_smd_1206 v12.step
3.20 x 1.60 x 0.59 mm

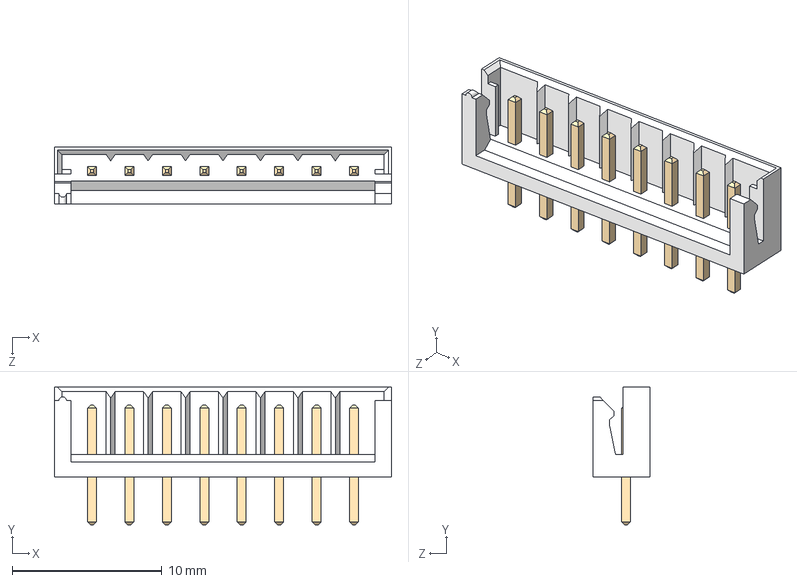
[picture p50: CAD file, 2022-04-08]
3D Models/EH 2.50 Connectors/STEP/BB-Top_Entry_Type/JST-B8B-EH-A.STEP
22.5 x 9.20 x 3.80 mm

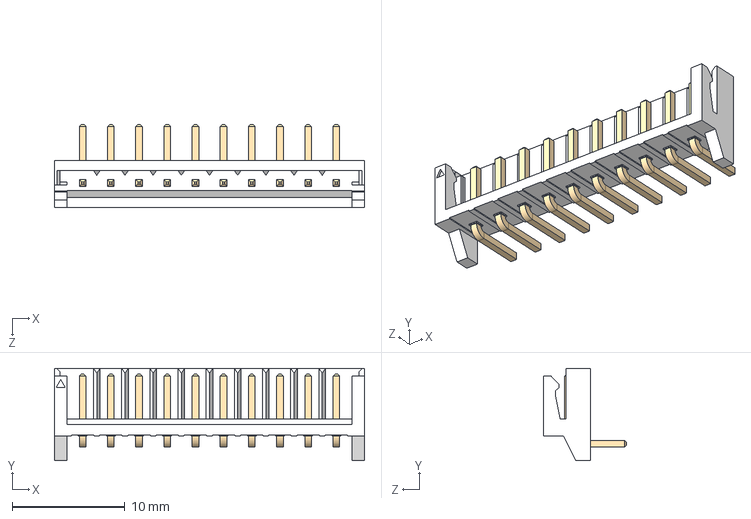
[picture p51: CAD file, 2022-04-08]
3D Models/EH 2.50 Connectors/STEP/SB-Side_Entry_Type/JST-S10B-EH-A.STEP
27.5 x 8.20 x 7.40 mm

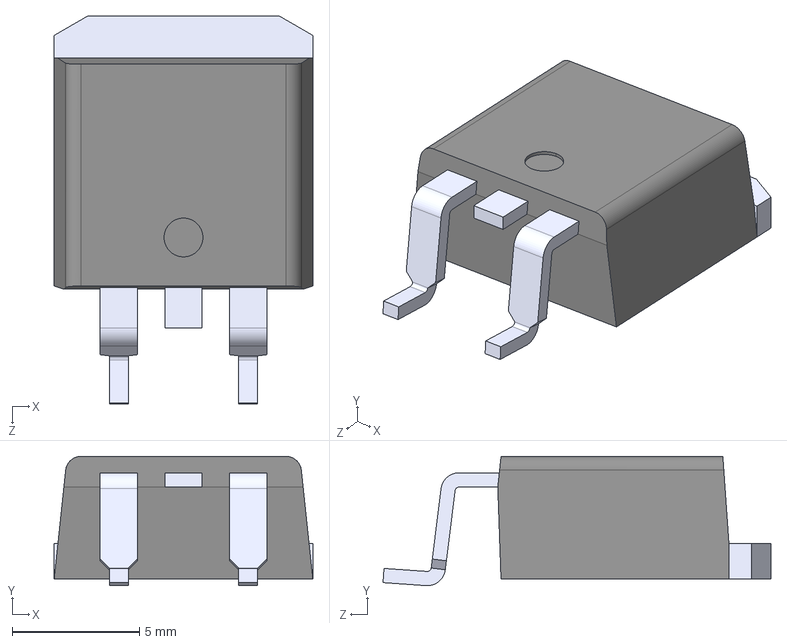
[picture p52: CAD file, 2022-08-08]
3D Models/IRF9530NSPBF.step
10.2 x 5.08 x 15.2 mm

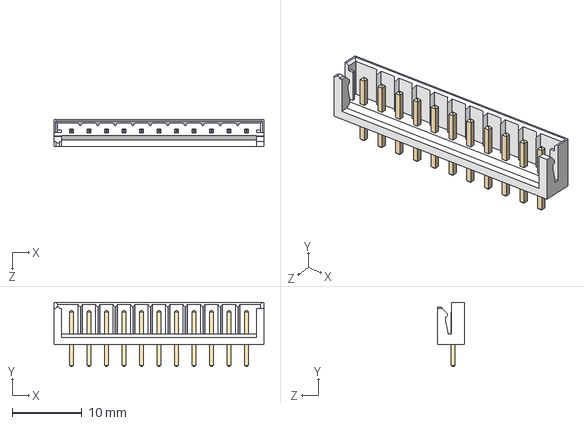
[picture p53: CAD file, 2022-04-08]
3D Models/EH 2.50 Connectors/STEP/BB-Top_Entry_Type/JST-B11B-EH-A.STEP
30.0 x 9.20 x 3.80 mm

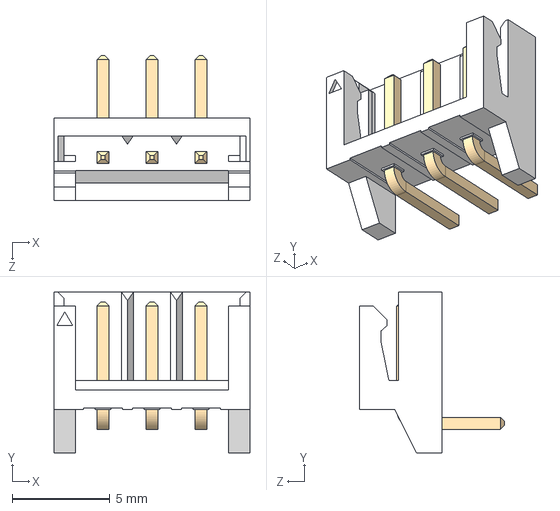
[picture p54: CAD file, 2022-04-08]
3D Models/EH 2.50 Connectors/STEP/SB-Side_Entry_Type/JST-S3B-EH-A.STEP
10.0 x 8.20 x 7.40 mm

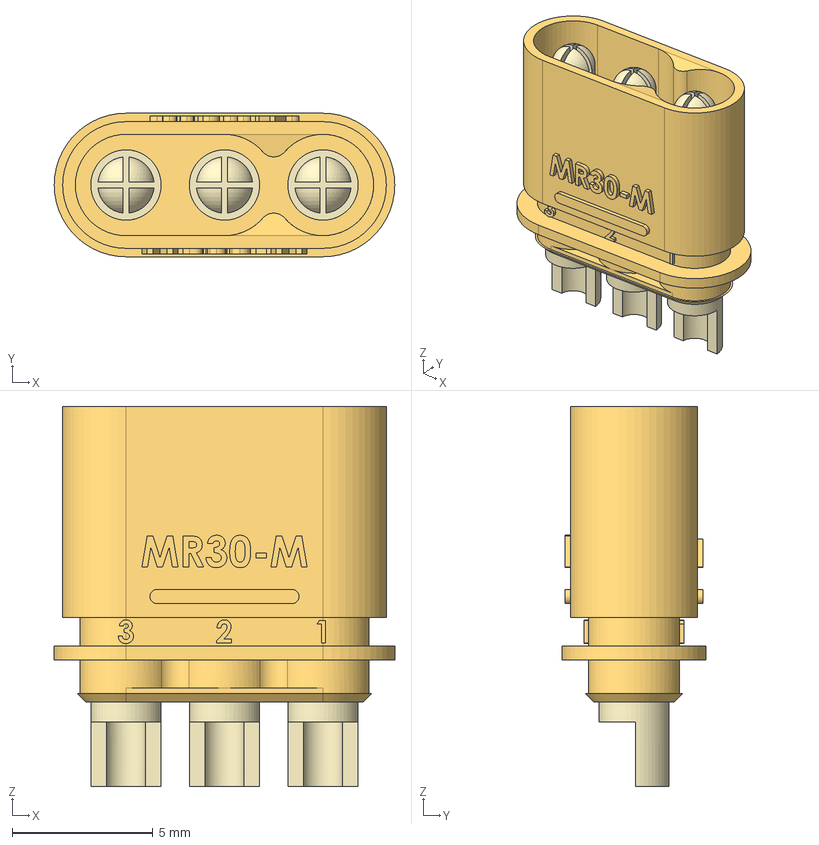
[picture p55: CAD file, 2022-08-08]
3D Models/MR30-M connector v1.step
12.1 x 5.10 x 13.5 mm

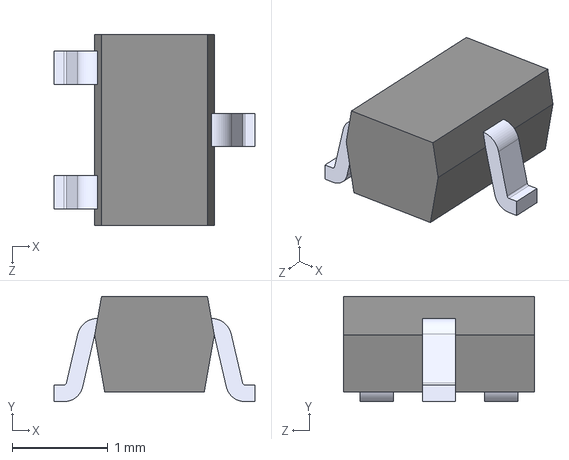
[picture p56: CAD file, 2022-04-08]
3D Models/BS170F.STEP
2.10 x 1.10 x 2.00 mm

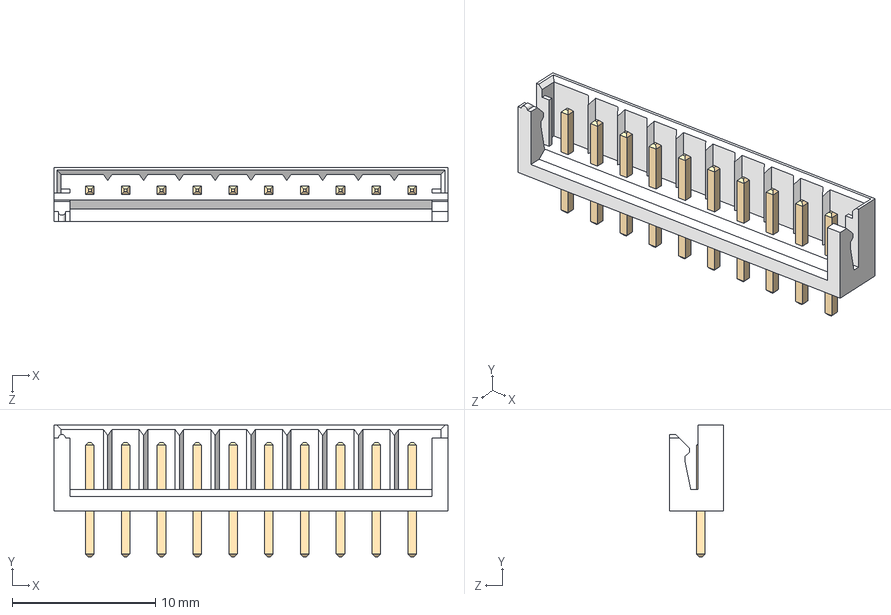
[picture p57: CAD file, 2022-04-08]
3D Models/EH 2.50 Connectors/STEP/BB-Top_Entry_Type/JST-B10B-EH-A.STEP
27.5 x 9.20 x 3.80 mm

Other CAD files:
3D Models/EH 2.50 Connectors/STEP/SB-Side_Entry_Type/JST-S2B-EH-A.STEP
3D Models/EH 2.50 Connectors/STEP/BB-Top_Entry_Type/JST-B6B-EH-A.STEP
3D Models/EH 2.50 Connectors/STEP/SB-Side_Entry_Type/JST-S11B-EH-A.STEP
3D Models/everlight-3MM-LED-YELLOW.step
3D Models/Ceramic_Capacitor_0805_h24mil v6.step
3D Models/EH 2.50 Connectors/SOURCE/BB-Top_Entry_Type/JST-B2B-EH-A.SLDPRT
3D Models/EH 2.50 Connectors/SOURCE/BB-Top_Entry_Type/JST-B3B-EH-A.SLDPRT
3D Models/EH 2.50 Connectors/SOURCE/SB-Side_Entry_Type/JST-S2B-EH-A.SLDPRT
3D Models/EH 2.50 Connectors/SOURCE/SB-Side_Entry_Type/JST-S3B-EH-A.SLDPRT
3D Models/EH 2.50 Connectors/STEP/BB-Top_Entry_Type/JST-B12B-EH-A.STEP
3D Models/EH 2.50 Connectors/STEP/BB-Top_Entry_Type/JST-B13B-EH-A.STEP
3D Models/EH 2.50 Connectors/STEP/BB-Top_Entry_Type/JST-B14B-EH-A.STEP
3D Models/EH 2.50 Connectors/STEP/BB-Top_Entry_Type/JST-B15B-EH-A.STEP
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

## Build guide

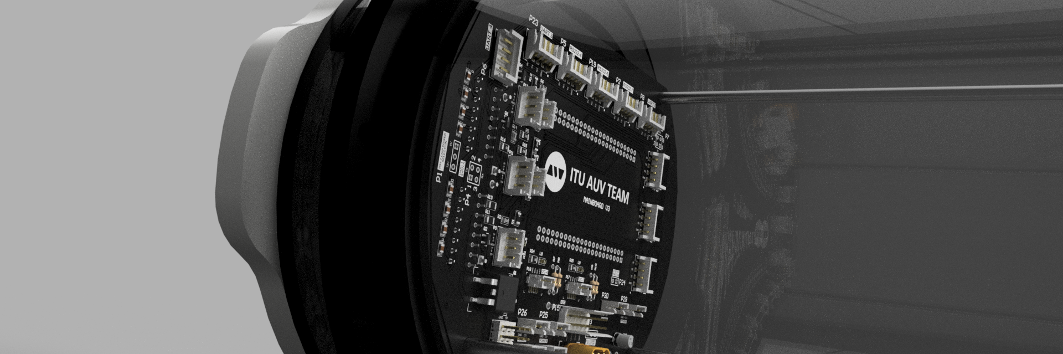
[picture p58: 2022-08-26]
Media/pictures/assembly-3.png

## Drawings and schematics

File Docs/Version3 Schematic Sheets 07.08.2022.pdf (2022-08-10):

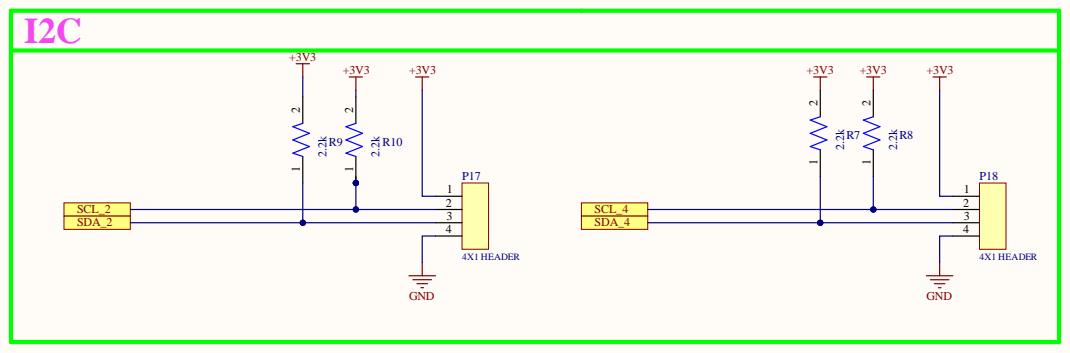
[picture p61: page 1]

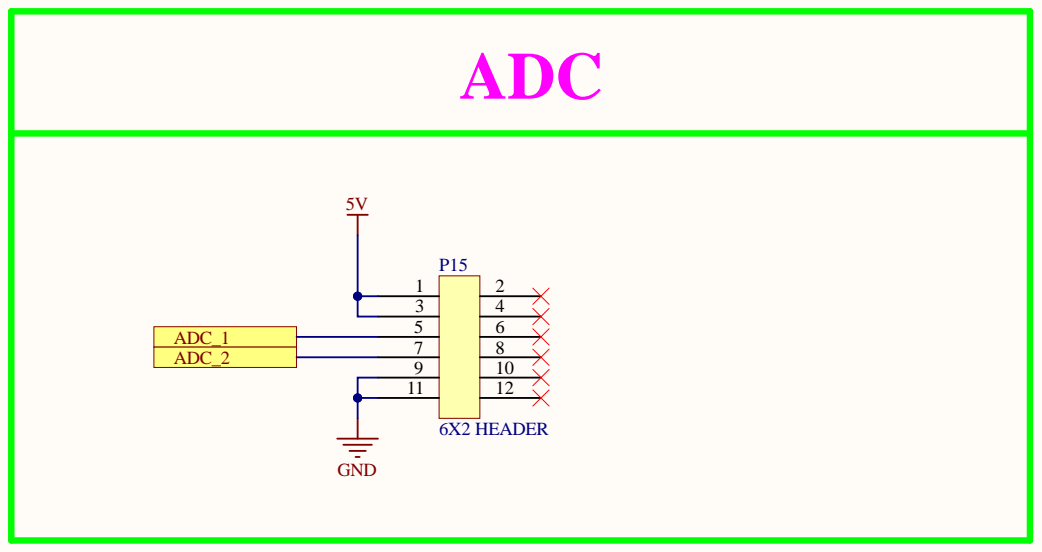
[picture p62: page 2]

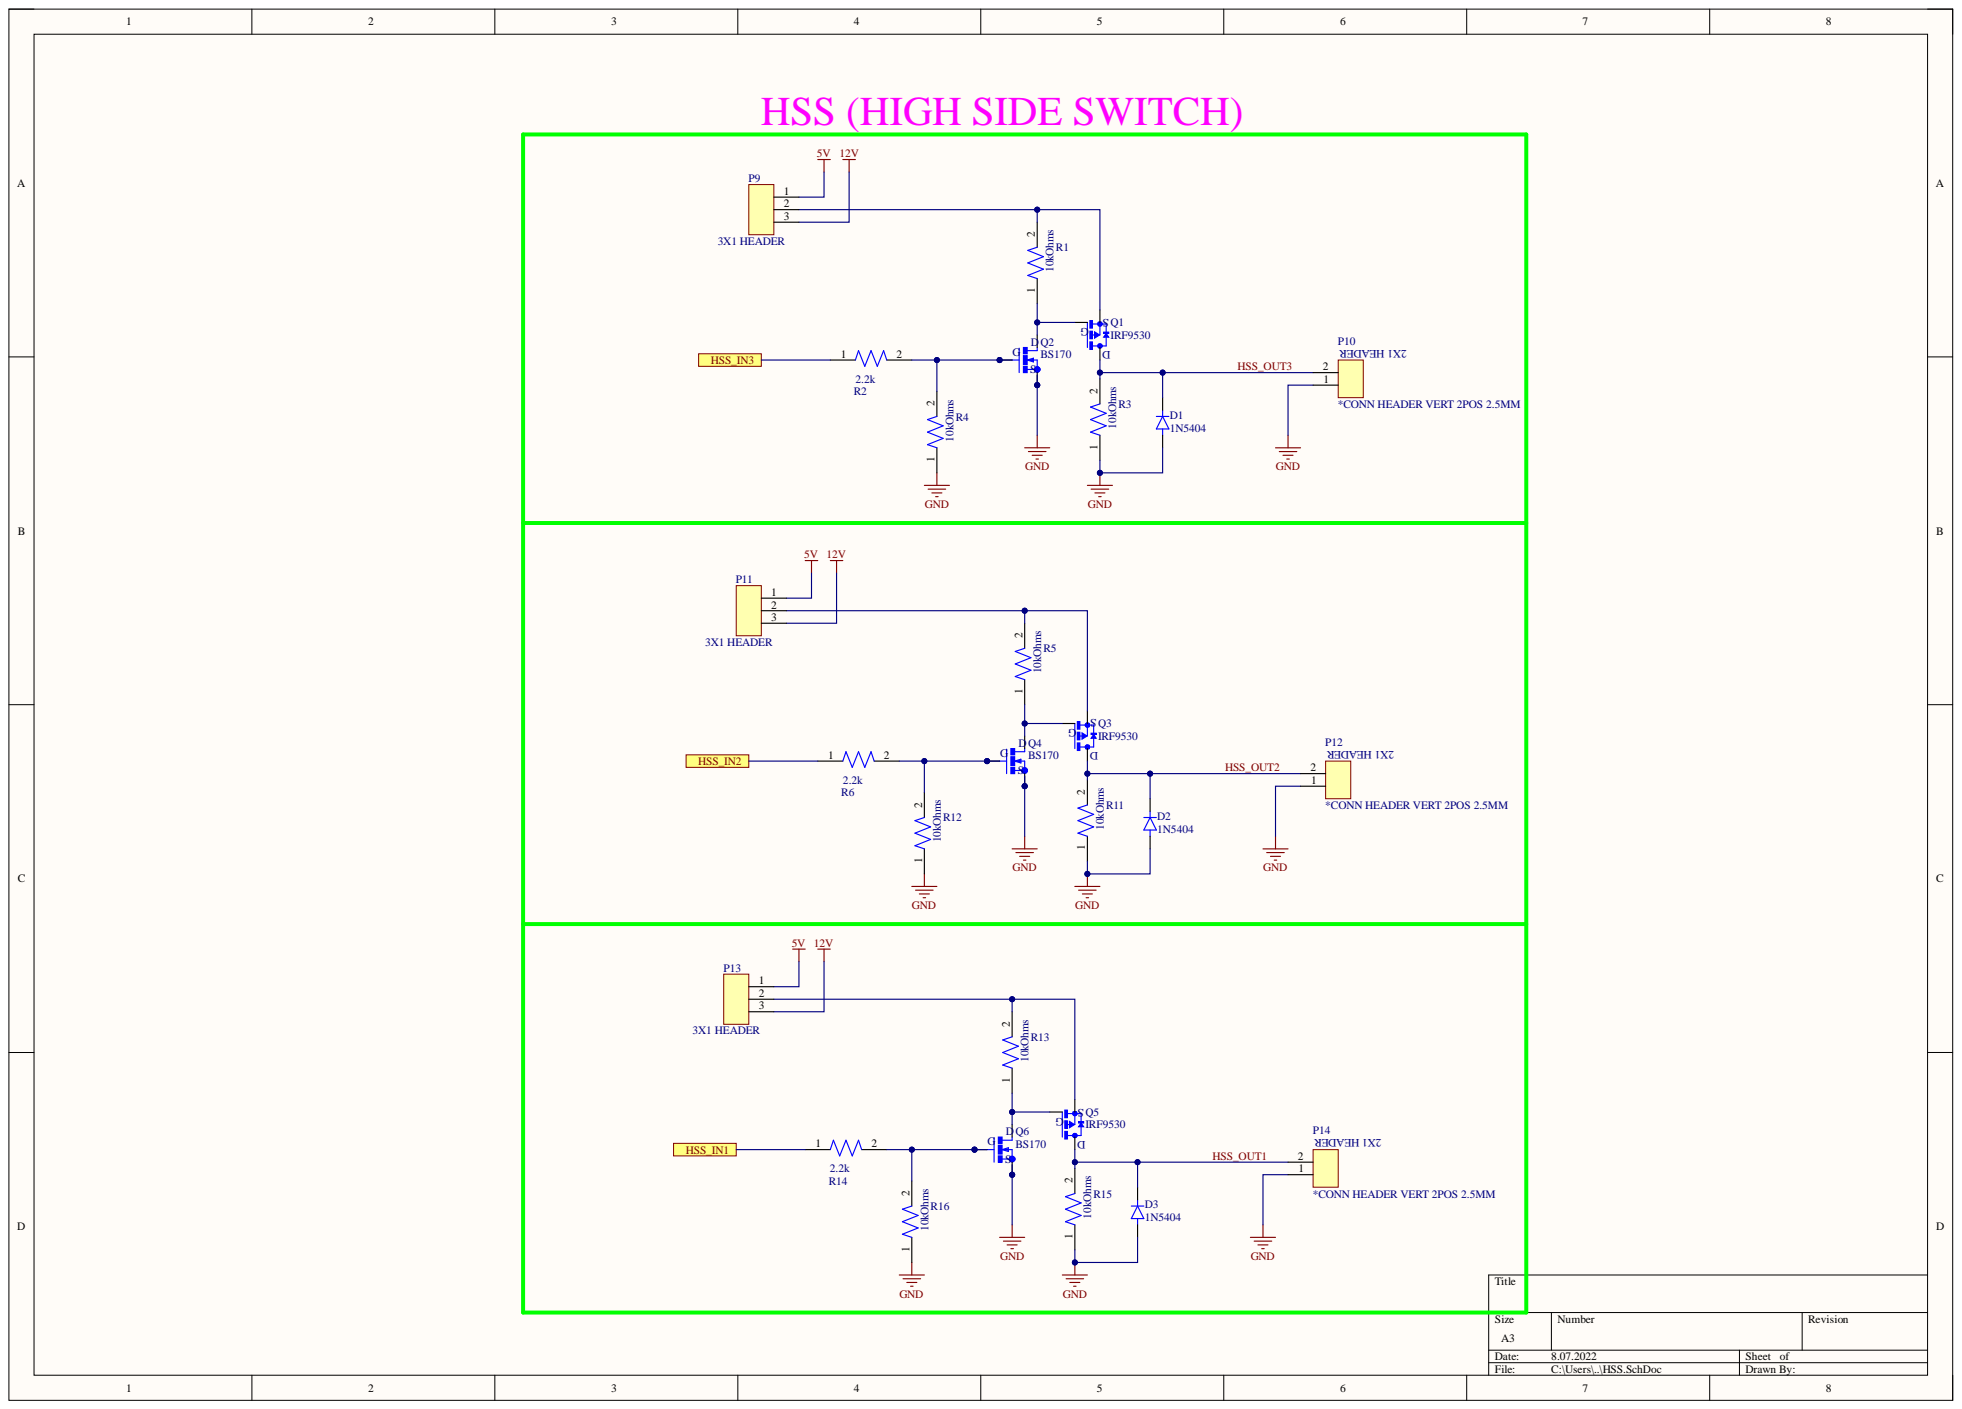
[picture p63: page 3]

HSS (HIGH SIDE SWITCH)

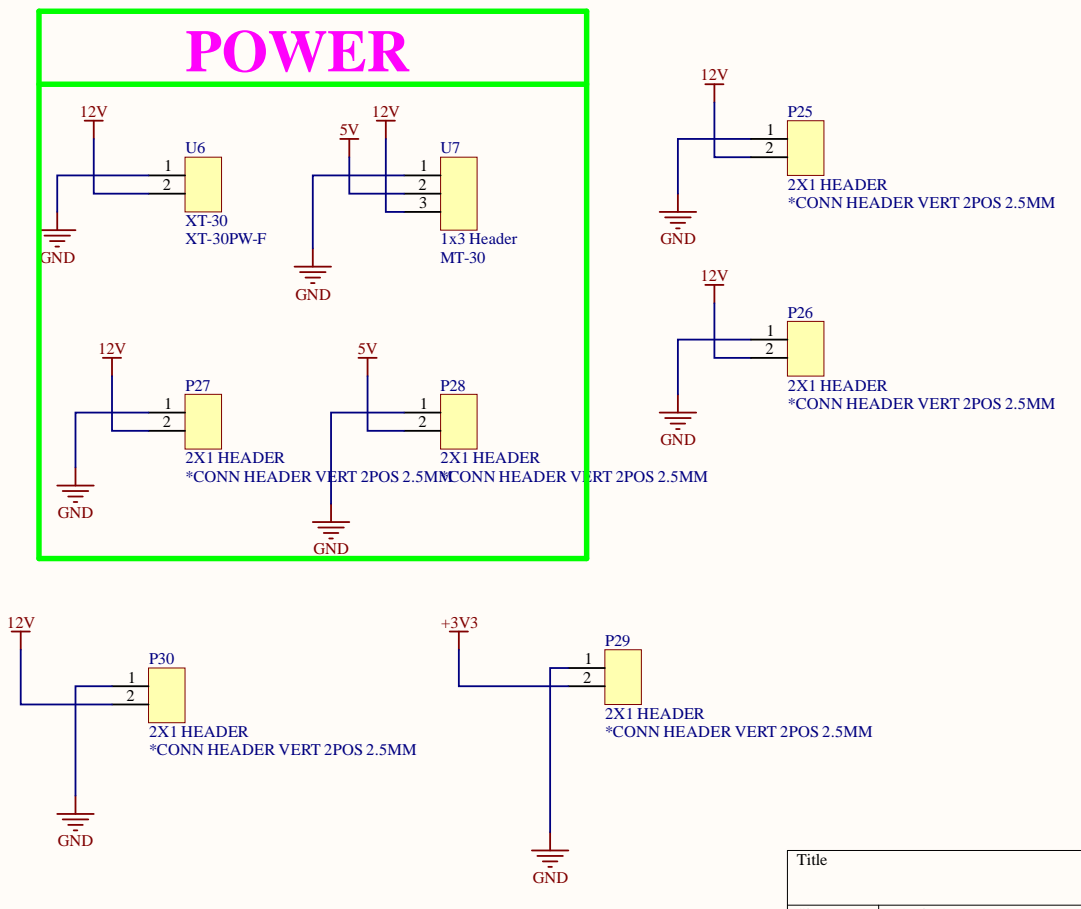
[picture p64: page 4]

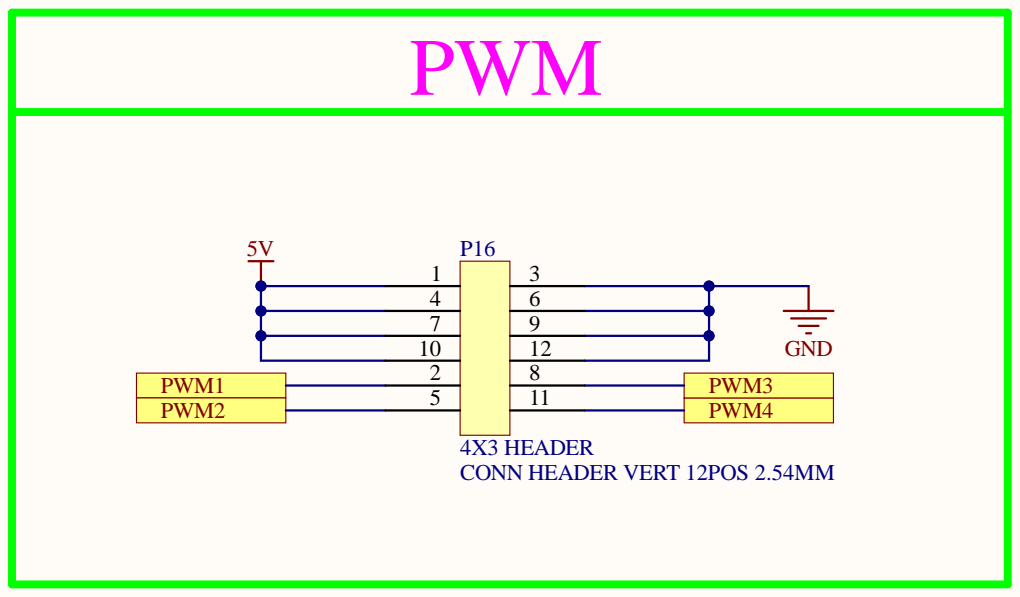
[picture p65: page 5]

10 | 12 | GND

PWM1 | 5 | 11 | PWM3
PWM2 | | | PWM4

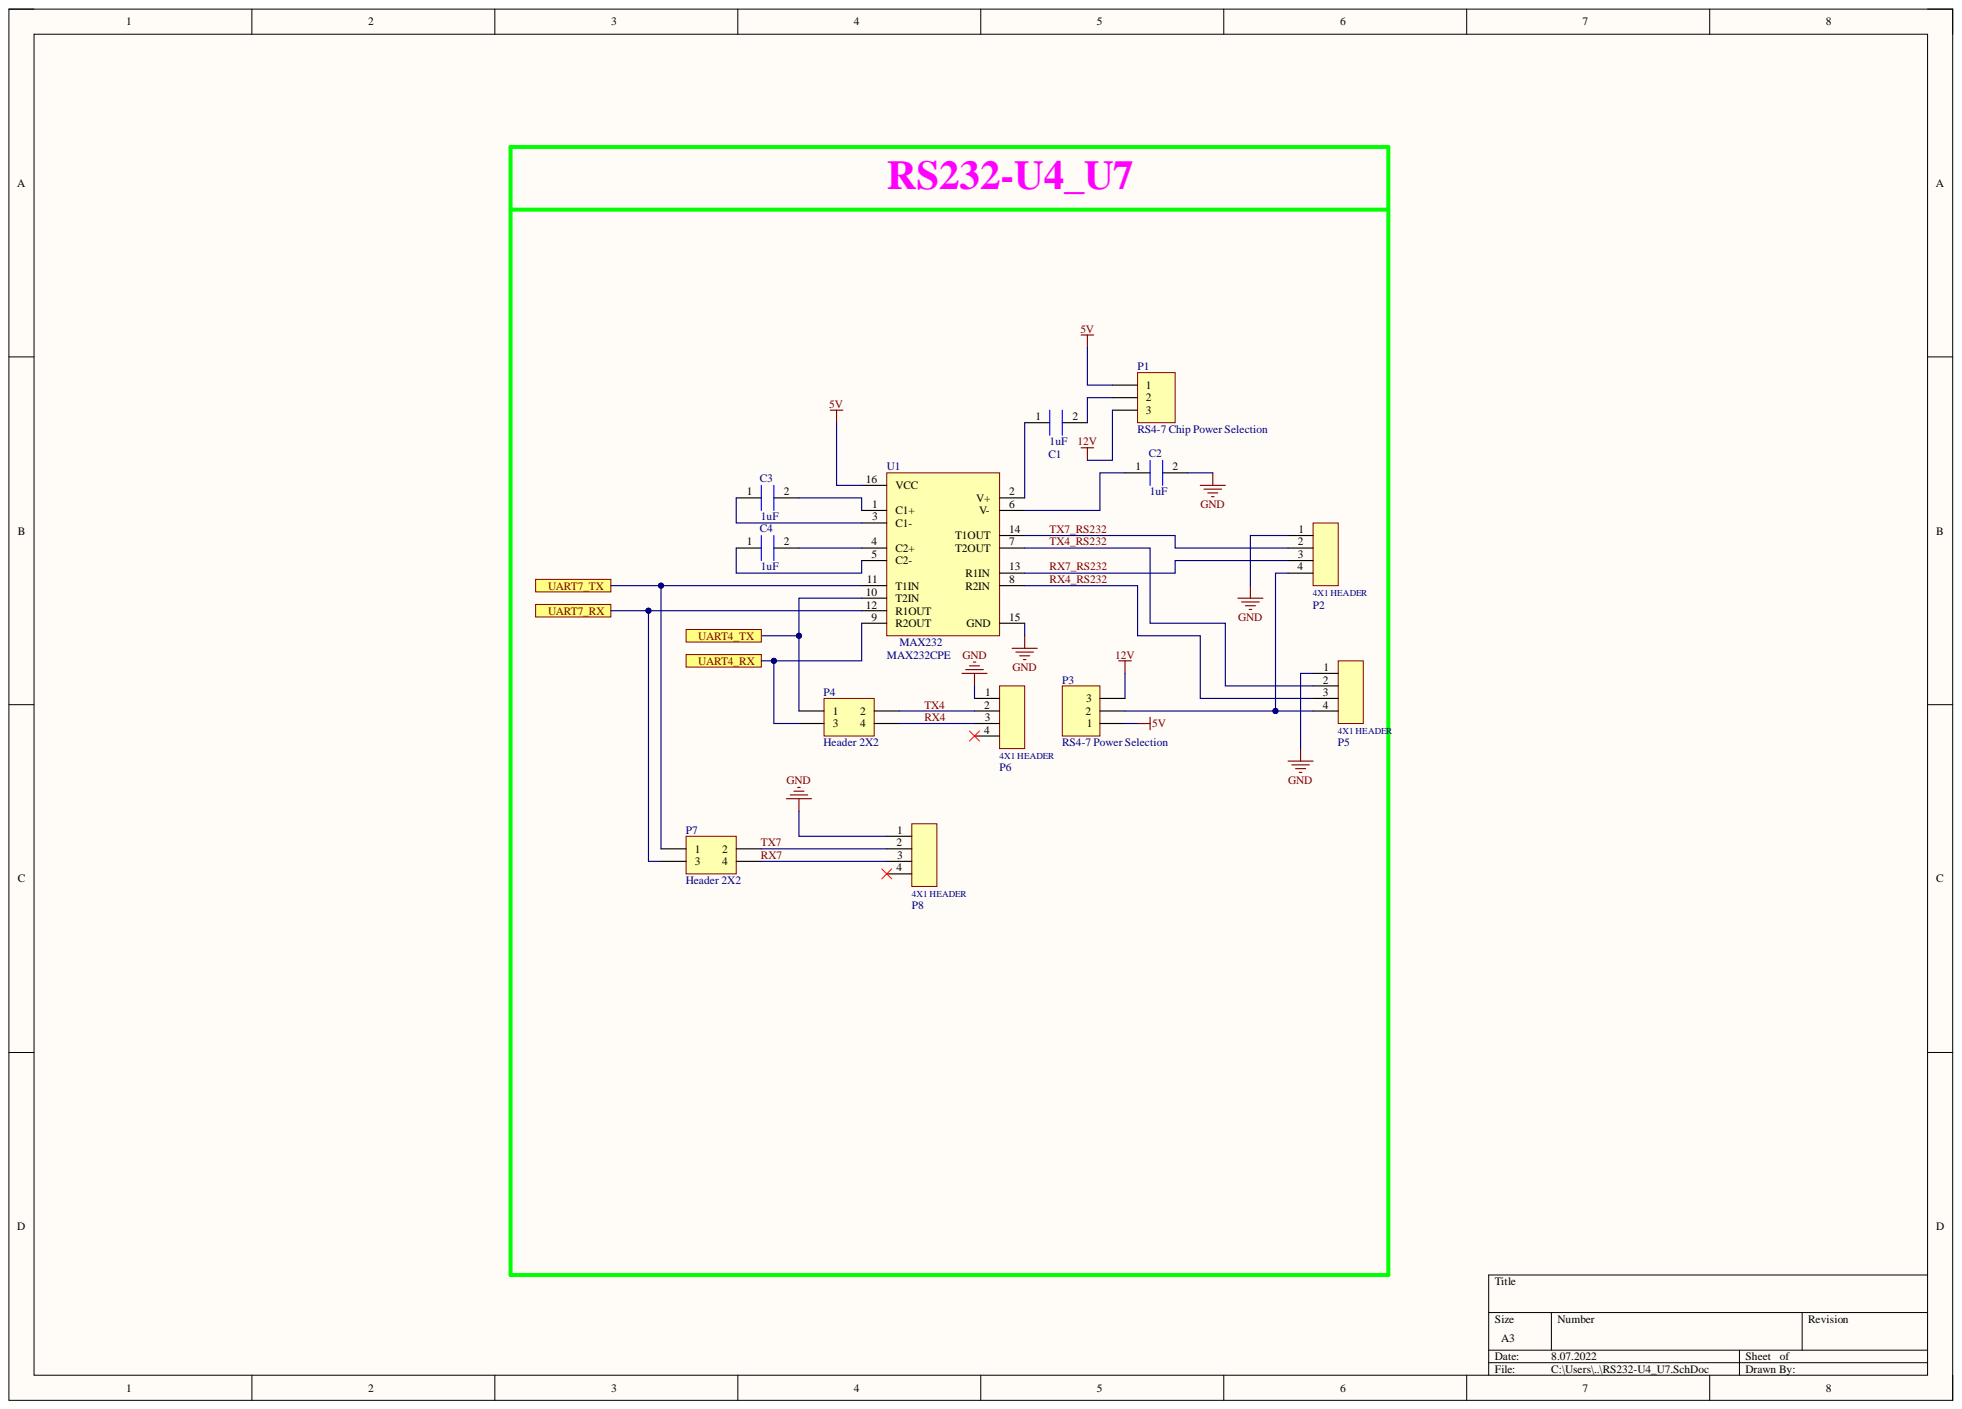
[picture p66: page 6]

UART7_RX | R2OUT 9

R1OUT 12

UART4_RX | GND

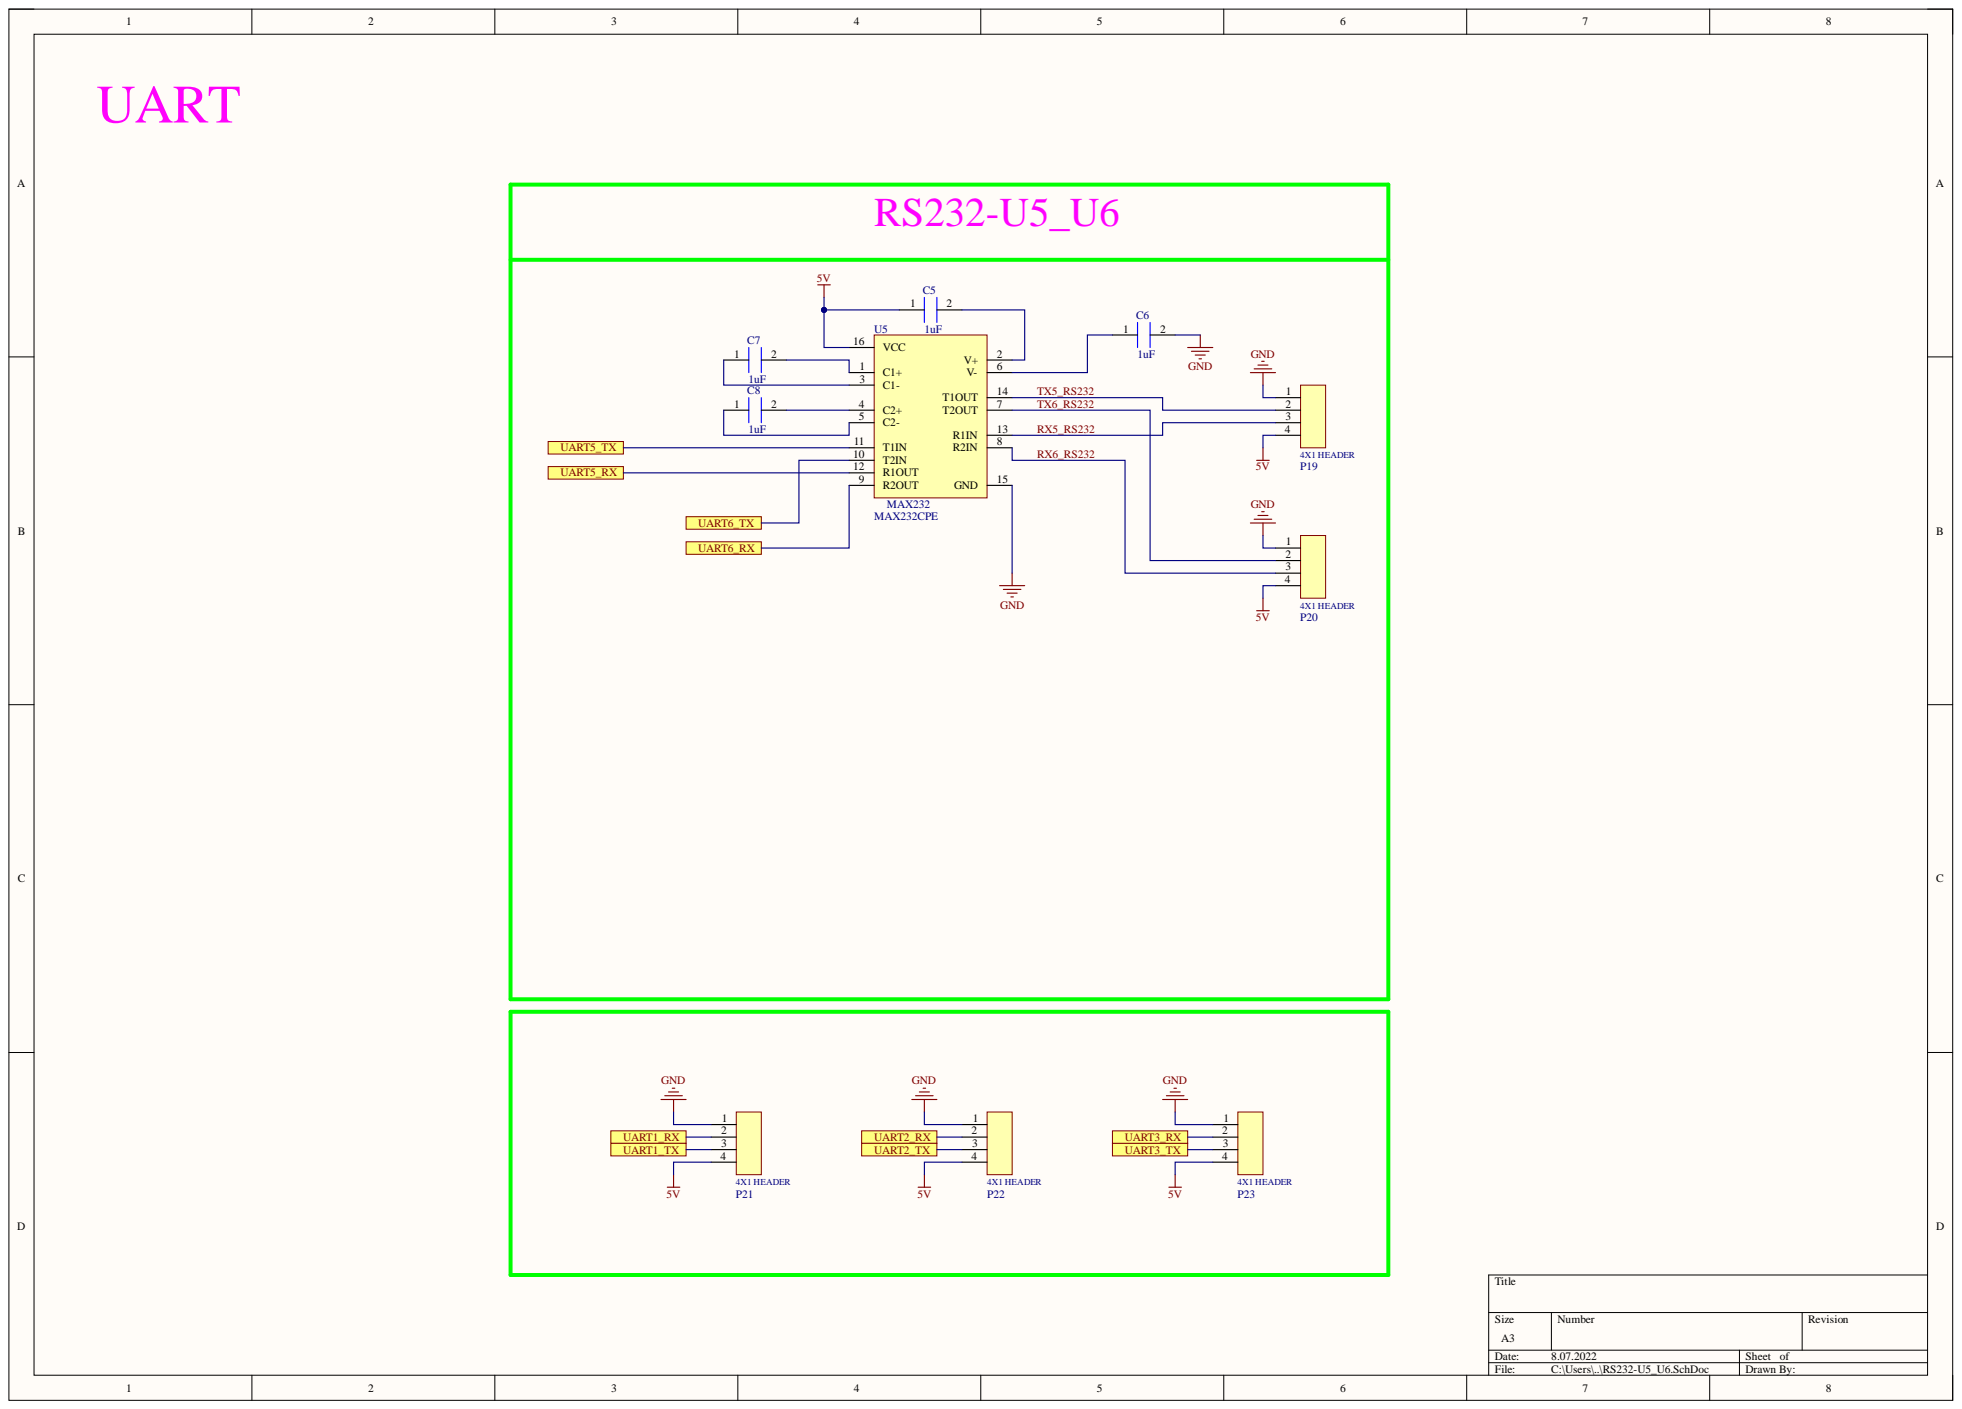
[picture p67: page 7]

U5
VCC 16

R1OUT 12 | 5V GND

UART5_RX | R2OUT 9

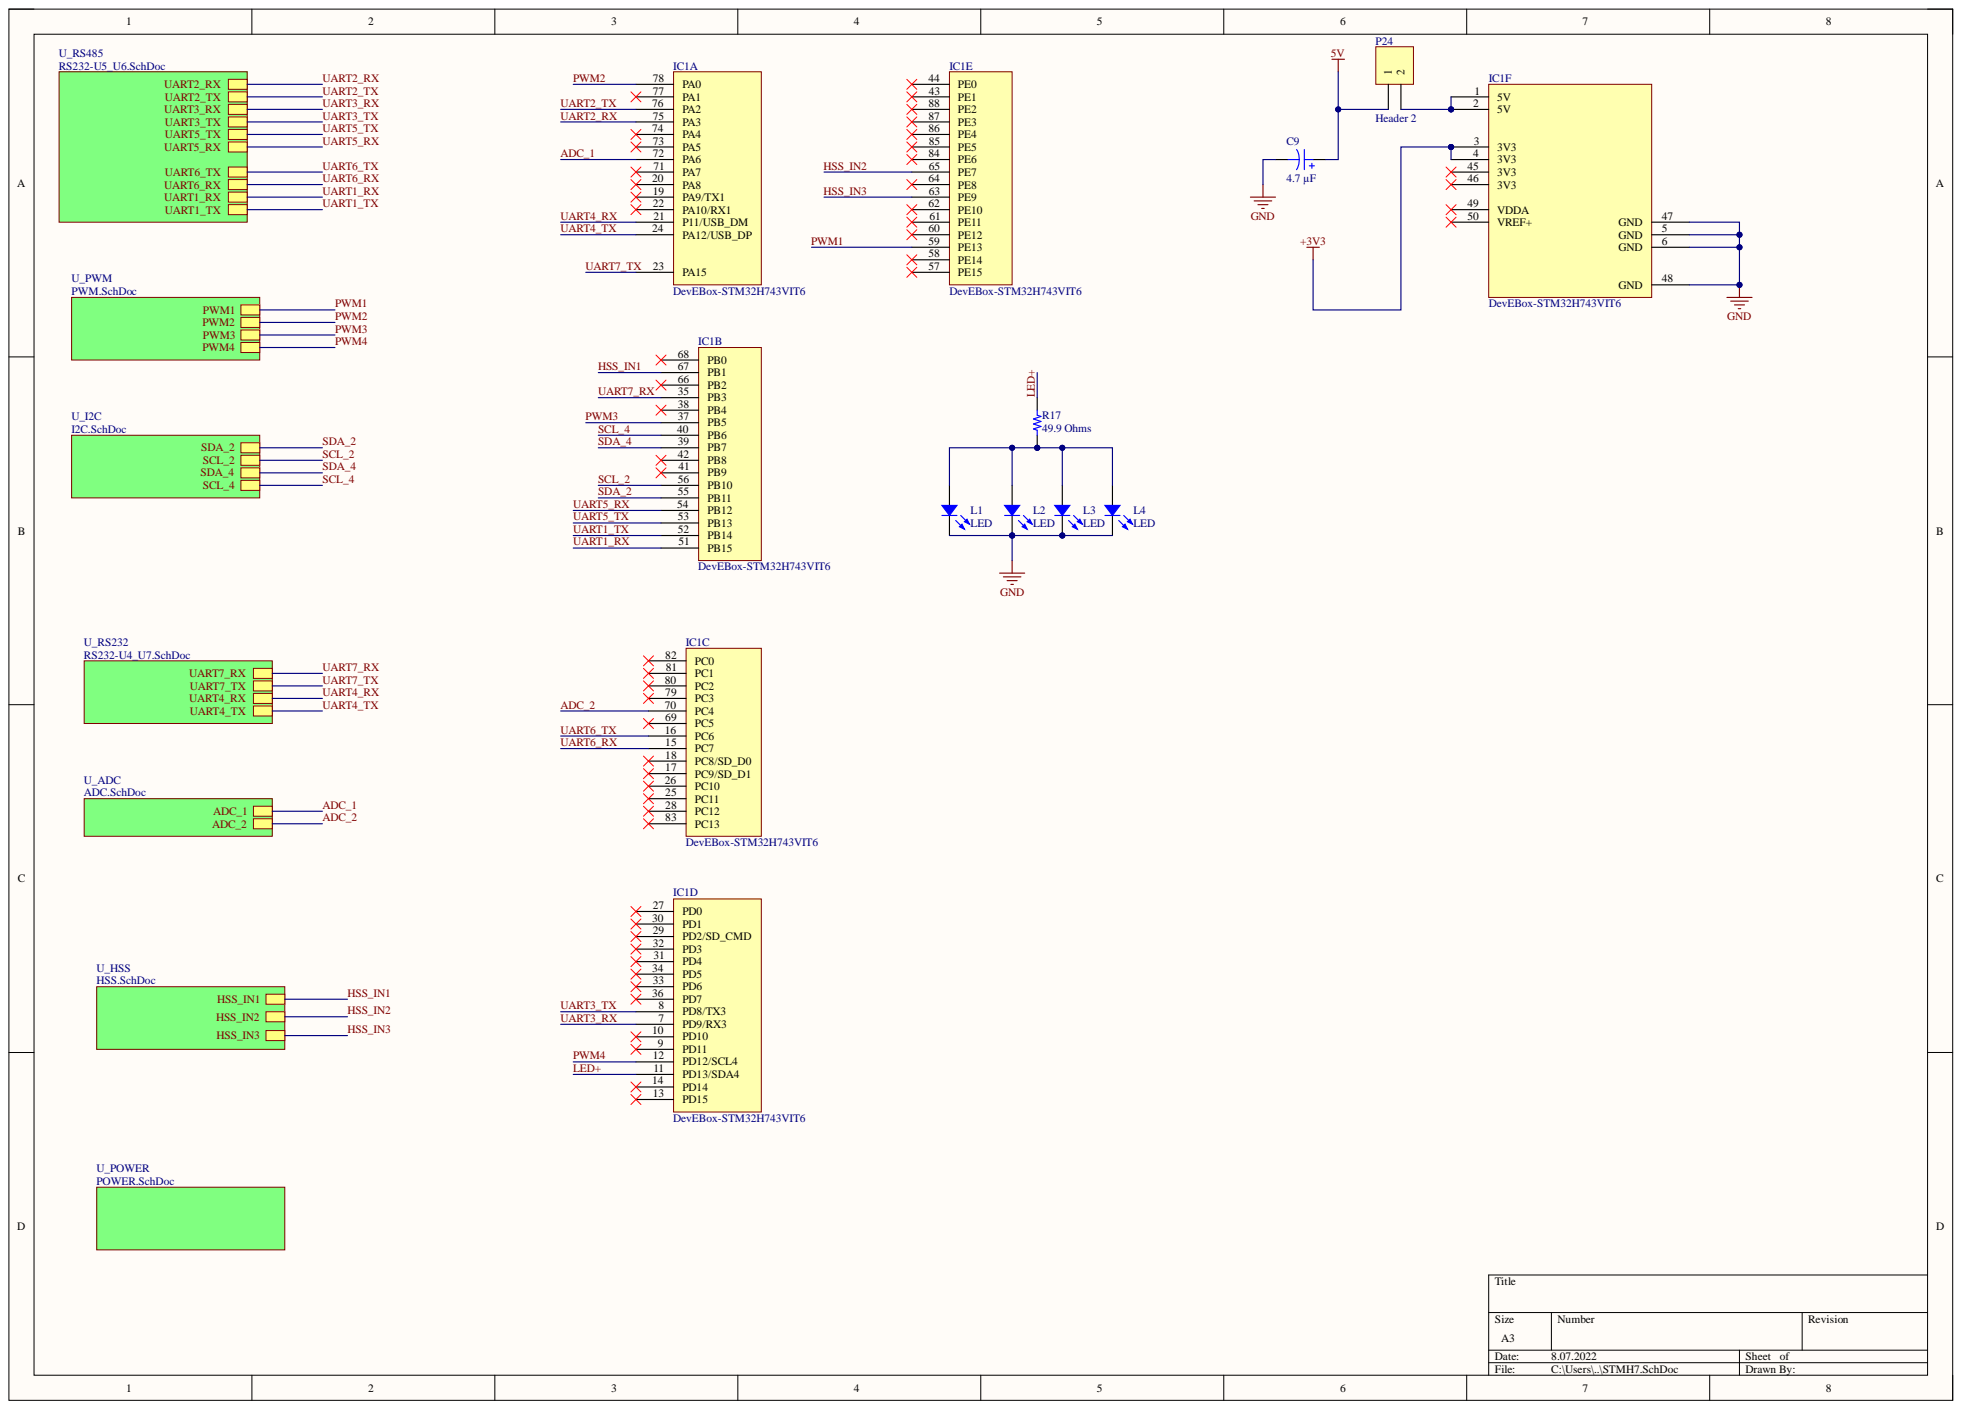
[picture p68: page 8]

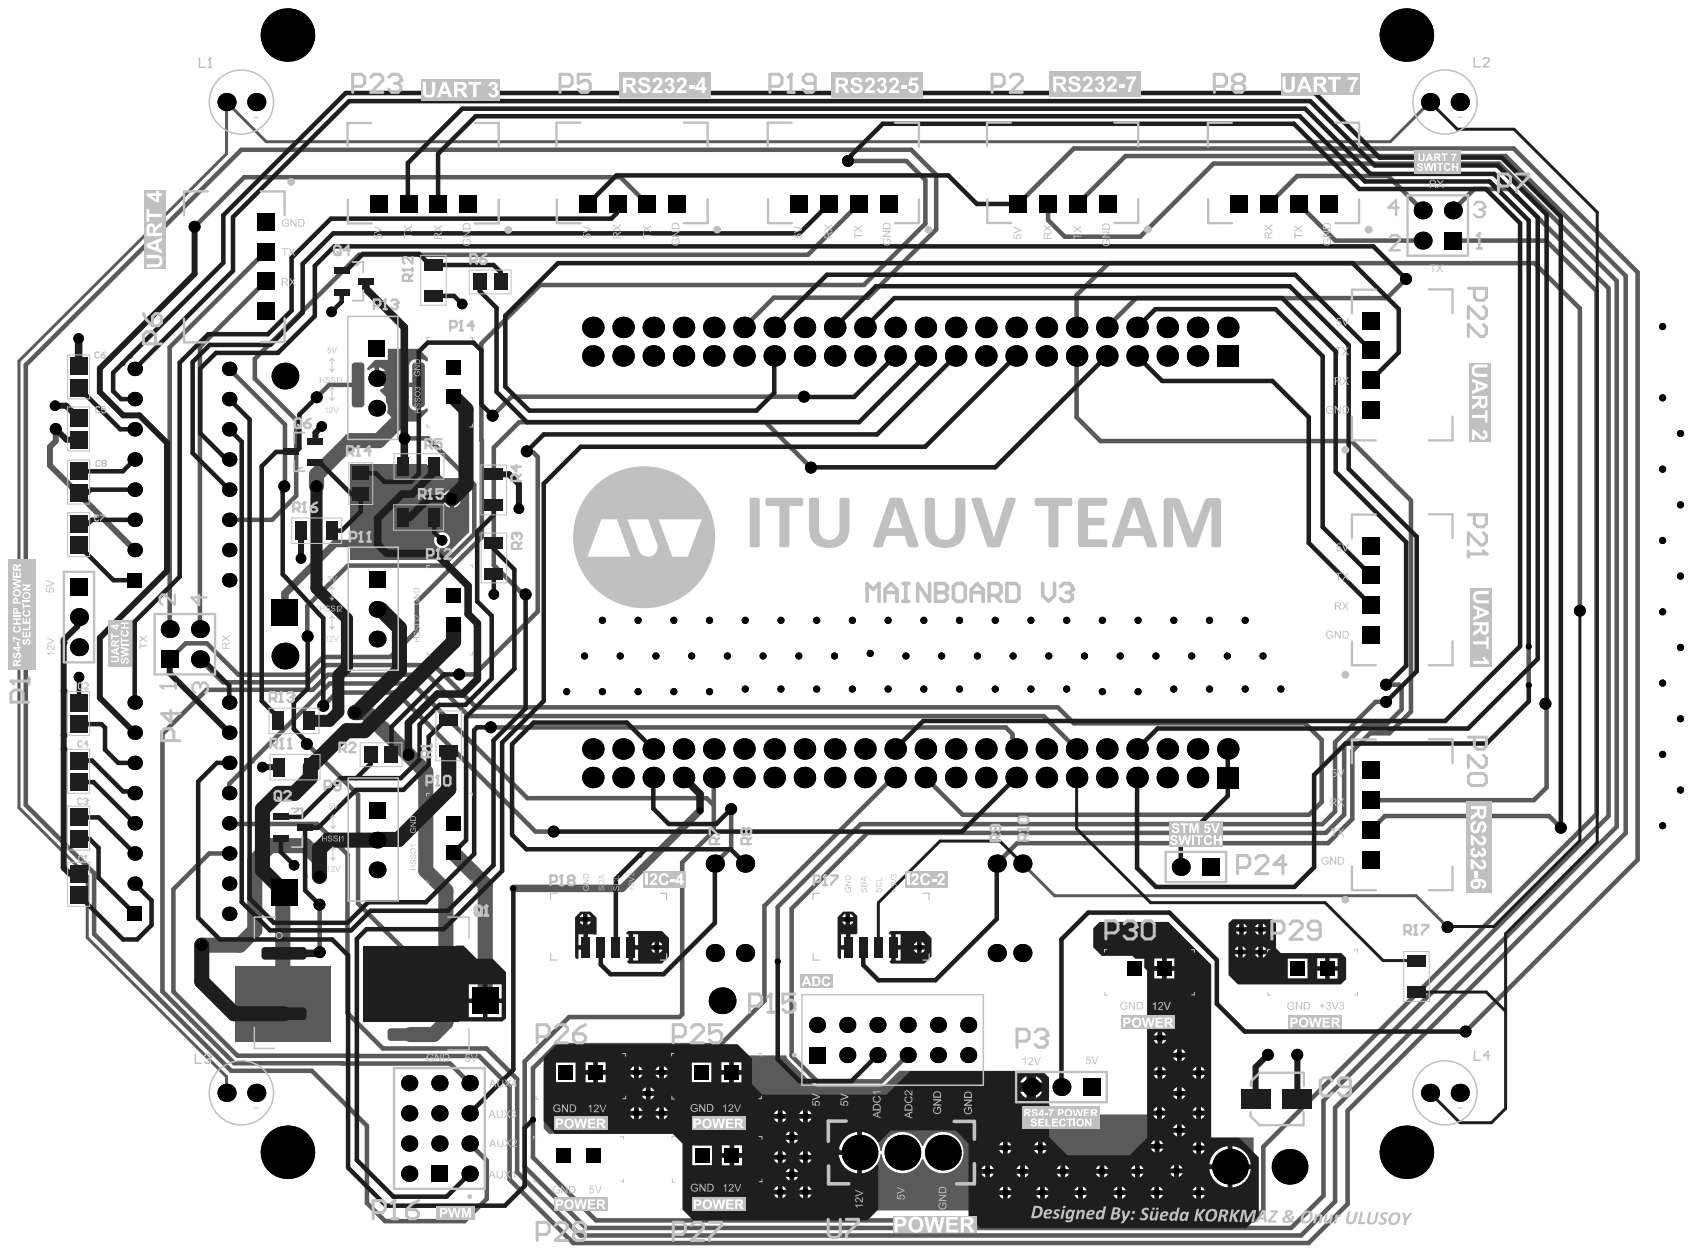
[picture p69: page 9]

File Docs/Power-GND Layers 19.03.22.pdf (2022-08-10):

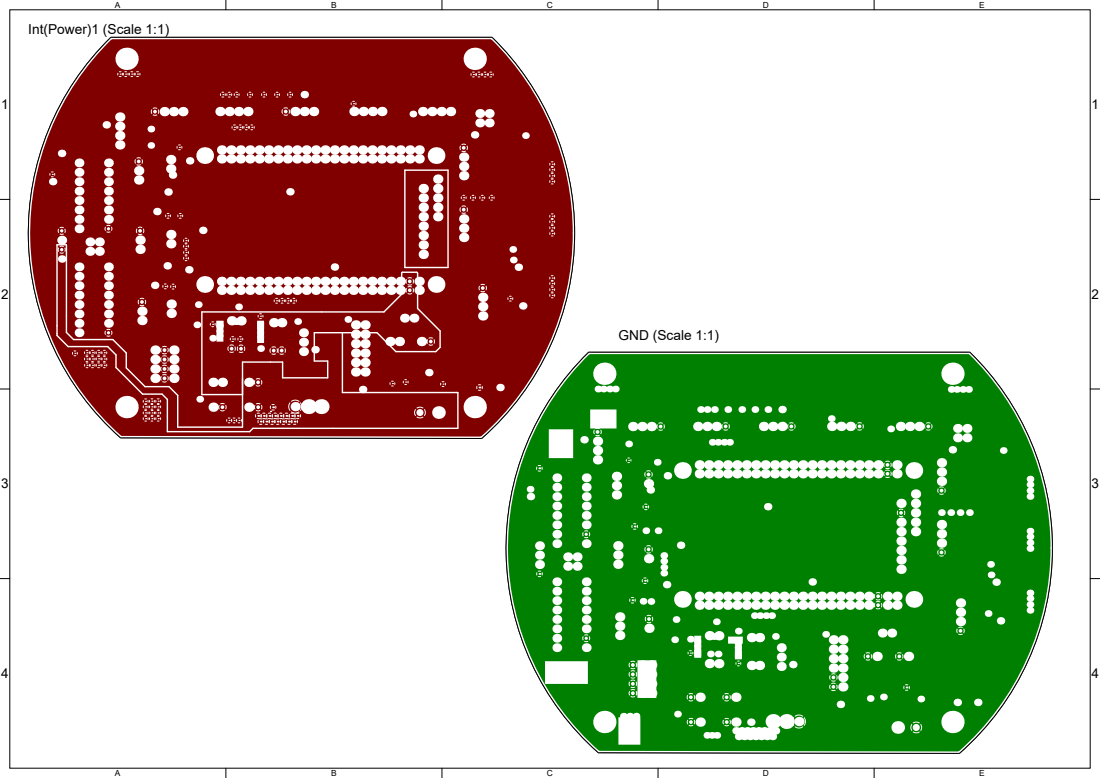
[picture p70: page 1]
GND (Scale 1:1)

Int(Power)1 (Scale 1:1)

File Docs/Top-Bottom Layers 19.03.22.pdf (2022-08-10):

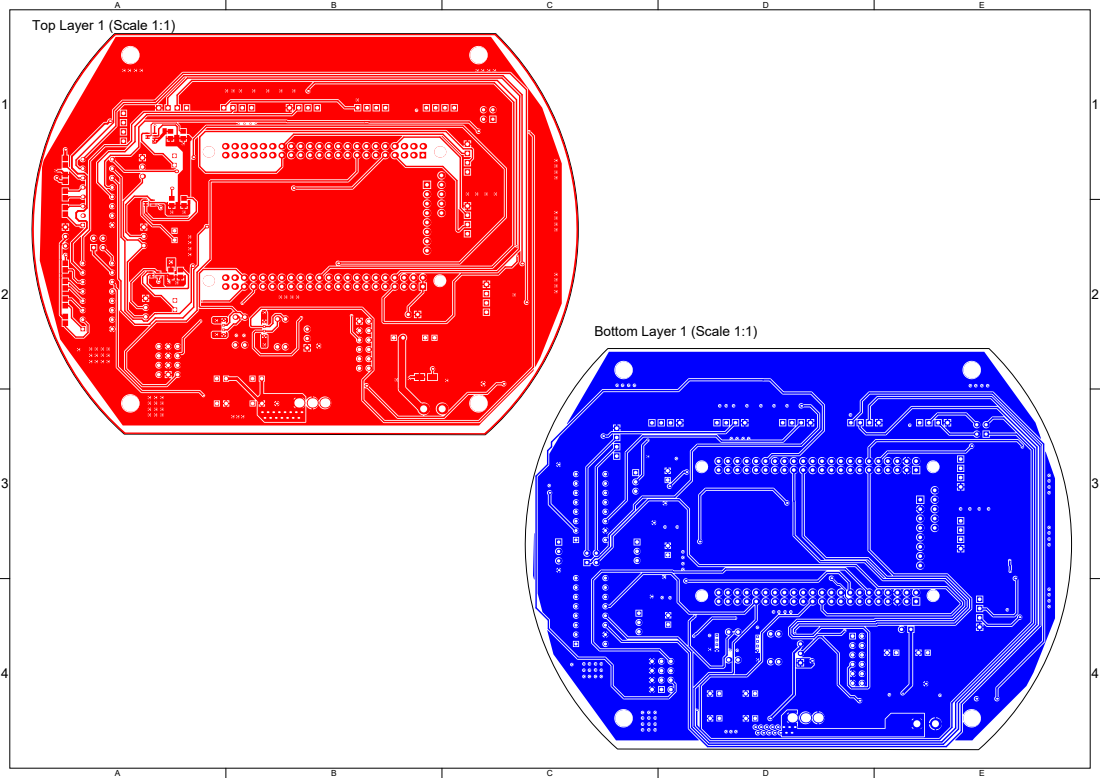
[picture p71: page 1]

Top Layer 1 (Scale 1:1)

Bottom Layer 1 (Scale 1:1)

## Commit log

2021-12-18 Begin project with EH 2.50 Connectors for communications
    [JST-B10B-EH-A.STEP, JST-B11B-EH-A.STEP, JST-B12B-EH-A.STEP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]
2022-01-03 Enrich library with BS170F
    [BS170F.STEP]
2022-01-12 Include BS170 schematic and footprint component in Altium library
2022-01-19 Incorporate a second variant of BS170 N-Channel MOSFET
    [bs170fta.step]
2022-02-14 Append LED models for easy debug as decided
    [SMD_0805LED_YEL.STEP, everlight-3MM-LED-YELLOW.step]
2022-02-15 Add 1N5404 schematic and footprint to the Altium library
2022-02-22 Add draft of HSS Circuit for reference
2022-02-27 Include IRF9530 schematic and footprint to the Altium library
2022-03-02 Add PWM schematic sheet to drive additional motors
    [PWM.SchDoc]
2022-03-06 Incorporate RS232-U4_U7 communication schematic
    [RS232-U4_U7.SchDoc]
2022-03-10 Add new resistor footprints to library
2022-03-12 Include ADC schematic for data acquirement necessitiess
    [ADC.SchDoc]
2022-03-18 Add power schematic sheet to manage power distribution
    [POWER.SchDoc]
2022-03-19 Store layout of Power-GND layers for reference
2022-03-23 Embed RS232-U5_U6 communication schematic
    [RS232-U5_U6.SchDoc]
2022-03-27 Add High Side Switch schematic sheet for power management
    [HSS.SchDoc]
2022-03-30 Insert I2C schematic sheet for peripheral communication
    [I2C.SchDoc]
2022-03-30 Add DPAK508P1524X483-3N footprint into the library
2022-03-31 Include STMH7 as the main/parent schematic sheet
    [STMH7.SchDoc]
2022-04-03 Add LED footprint to component library
2022-04-04 Configure project settings including libraries
    [PCB_MAIN_BOARD.PrjPcb]
2022-04-08 Include surface-mount ceramic capacitor
    [Ceramic_Capacitor_0805_h24mil v6.step]
2022-04-15 Analyze High Side Switch (HSS) circuit with simulation
2022-04-18 Include new schematic library Schlib1
2022-04-18 Provide PCB design document for mainboard
2022-04-25 Extend libraries with PcbLib2021-2022 sublibrary
2022-05-15 Offer reference Power and GND layers with Power-GND-Layers.PCBDwf
2022-05-20 Update with 4P connector for versatile interfacing
    [DF13-4P-1.25V--3DModel-STEP-1.STEP]
2022-05-27 Provide reference Top and Bottom layers with Top-Bottom-Layers.PCBDwf
2022-06-15 Extend component list with IRF9530NSPBF
    [IRF9530NSPBF.step]
2022-07-15 Add MR30-M power connector to output power
    [MR30-M connector v1.step]
2022-07-29 Advance towards manufacturing with Gerber files for Version 3
    [MAINBOARD.GBL, MAINBOARD.GBO, MAINBOARD.GBP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]
2022-08-08 Add surface-mount resistor to the library to improve visuality
    [resistencia_smd_1206 v12.step]
2022-08-10 Archive version 3 schematic sheets
2022-08-17 Write board description and electronics design
2022-08-17 Write connectivity and power circuits documentations
